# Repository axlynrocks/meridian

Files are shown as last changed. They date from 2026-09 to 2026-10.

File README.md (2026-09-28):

# meridian

note: this project is my attempt at merging my 2 biggest interests and speedrunning them in 2 months and the culmination of about half a year's worth of _severe_ procrastination

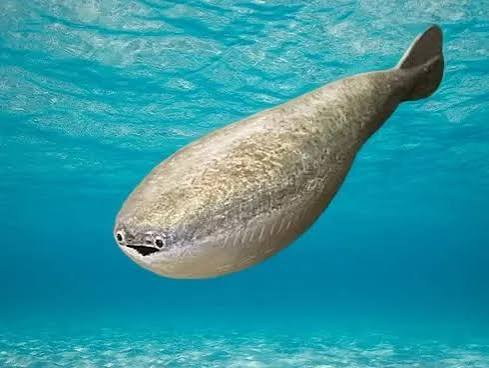
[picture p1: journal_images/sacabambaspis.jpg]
sacabambaspis


second note: no pics yet, will have them once mk. 1 is done!!!

## what is this?

a hybrid autonomous underwater research vehicle for me to use researching coastal waters!

as of meridian mk. 1, it uses 6 thrusters in total for movement: 4 for yaw and forwards / backwards movement, and 2 for roll and upwards / downwards movement. with an acrylic shell with a polycarbonate dome for its inbuilt camera as well as a couple of aluminum mounting rods attached to the exterior, i can attach practically anything i want to it (but they're mostly going to be sensors anyway) and of course, all the stuff inside like the ESCs, FC, sensor board, power management board, carrier board for the compute module are all custom made by yours truly!

> "perpetually a work in progress" - me '26

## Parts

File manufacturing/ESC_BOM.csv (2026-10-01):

part | quantity | description | cost / unit (USD) | link | datasheet | distributor | manufacturer
STM32G071KBU6N | 1*4 | MCU for BLDC control | 2.49 | https://www.st.com/en/microcontrollers-microprocessors/stm32g071kb.html | https://www.st.com/resource/en/datasheet/stm32g071kb.pdf | Digikey | STMicroelectronics
SIR696DP-T1-GE3 | 6*4 | MOSFETs | 1.71 | https://www.digikey.in/en/products/detail/vishay-siliconix/SIR696DP-T1-GE3/6707749 | https://www.vishay.com/docs/65689/sir696dp.pdf | Digikey | Vishay Siliconix
DRV8300DRGER | 1*4 | half-bridge gate driver | 0.88 | https://www.digikey.my/en/products/detail/texas-instruments/DRV8300DRGER/13918763 | https://www.ti.com/lit/ds/symlink/drv8300.pdf | Digikey | Texas Instruments
HT7550-1 | 1 | 5V voltage regulator | 0.25 | https://www.digikey.my/en/products/detail/umw/HT7550-1/17635253 | https://www.umw-ic.com/static/pdf/50f0291342dc480ca9b1da386971e0aa.pdf | Digikey | UMW
HT7533-1 | 1 | 3.3V voltage regulator | 0.25 | https://www.digikey.my/en/products/detail/umw/HT7533-1/17635239 | https://www.umw-ic.com/static/pdf/50f0291342dc480ca9b1da386971e0aa.pdf | Digikey | UMW
INA180A1IDBVR | 1*4 | current sense amplifier | 0.82 | https://www.digikey.com/en/products/detail/texas-instruments/INA180B1IDBVR/8105876 | https://www.ti.com/lit/ds/symlink/ina180.pdf | Digikey | Texas Instruments
1N4148W-HG3_A-08 | 3*4 | diode | 0.5 | https://www.digikey.com/en/products/detail/vishay-general-semiconductor-diodes-division/1N4148W-HG3-A-08/22145563 | https://www.vishay.com/docs/86357/1n4148w-g.pdf | Digikey | Vishay
TPS7A4501KTTR | 1 | adjustable voltage regulator | 3.7 | https://www.digikey.my/en/products/detail/texas-instruments/TPS7A4501KTTR/1908606 | https://www.ti.com/lit/ds/symlink/tps7a45.pdf | Digikey | Texas Instruments

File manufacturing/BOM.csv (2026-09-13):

part | quantity | description | cost / unit (USD) | link | datasheet | distributor | manufacturer
DFR1146 | 1 | SBC | 192.5 | https://www.digikey.my/en/products/detail/dfrobot/DFR1146/23028653 | https://docs.lattepanda.com/content/mu_edition/introduction/ | DigiKey | DFRobot
custom PCBs | 1 | to hold all the parts | ~400 | https://jlcpcb.com/ | N/A | JLCPCB | JLCPCB
BR-101052-200 | 1 | acrylic tube 200mm len. | 170 | https://bluerobotics.com/store/watertight-enclosures/locking-series/wte-locking-tube-r1-vp/ | https://bluerobotics.com/wp-content/uploads/2026/05/WTE-DATASHEET-RevC.5-MAY2026.pdf | BlueRobotics | BlueRobotics
BR-100495 | 2 | clear polycarbonate dome | 42 | https://bluerobotics.com/store/watertight-enclosures/locking-series/wte-end-cap-vp/ | https://bluerobotics.com/wp-content/uploads/2026/05/WTE-DATASHEET-RevC.5-MAY2026.pdf | BlueRobotics | BlueRobotics
BR-100665 | 1 | o-ring flange | 50 | https://bluerobotics.com/store/watertight-enclosures/locking-series/wte-flange-vp/ | https://bluerobotics.com/wp-content/uploads/2026/05/WTE-DATASHEET-RevC.5-MAY2026.pdf | BlueRobotics | BlueRobotics
BR-102993-002 | 1 | aluminum end cap 10x M10 | 42 | https://bluerobotics.com/store/watertight-enclosures/locking-series/wte-end-cap-vp/ | https://bluerobotics.com/wp-content/uploads/2026/05/WTE-DATASHEET-RevC.5-MAY2026.pdf | BlueRobotics | BlueRobotics
BR-100804 | 1 | pressure relief valve | 32 | https://bluerobotics.com/store/watertight-enclosures/enclosure-tools-supplies/prv-m10-asm/ | https://bluerobotics.com/wp-content/uploads/2026/05/WTE-DATASHEET-RevC.5-MAY2026.pdf | BlueRobotics | BlueRobotics
BR-100574 | 1 | o-ring pick | 0 | https://bluerobotics.com/store/watertight-enclosures/enclosure-tools-supplies/tool-o-ring-pick-r1/ | https://bluerobotics.com/wp-content/uploads/2026/05/WTE-DATASHEET-RevC.5-MAY2026.pdf | BlueRobotics | BlueRobotics
BR-103290-200 | 2 | narrow rails 200N | 29 | https://bluerobotics.com/store/watertight-enclosures/locking-series/watertight-enclosure-rails-set/ | https://bluerobotics.com/wp-content/uploads/2025/01/WTE-RAILS-DATASHEET-RevA-FEB2025.pdf | BlueRobotics | BlueRobotics
BR-103291-400 | 1 | rect. tray | 24 | https://bluerobotics.com/store/watertight-enclosures/locking-series/watertight-enclosure-rectangular-tray/ | https://bluerobotics.com/wp-content/uploads/2025/01/WTE-RAILS-DATASHEET-RevA-FEB2025.pdf | BlueRobotics | BlueRobotics
BR-103292-400 | 3 | circ. tray | 27 | https://bluerobotics.com/store/watertight-enclosures/locking-series/watertight-enclosure-circular-tray/ | https://bluerobotics.com/wp-content/uploads/2025/01/WTE-RAILS-DATASHEET-RevA-FEB2025.pdf | BlueRobotics | BlueRobotics

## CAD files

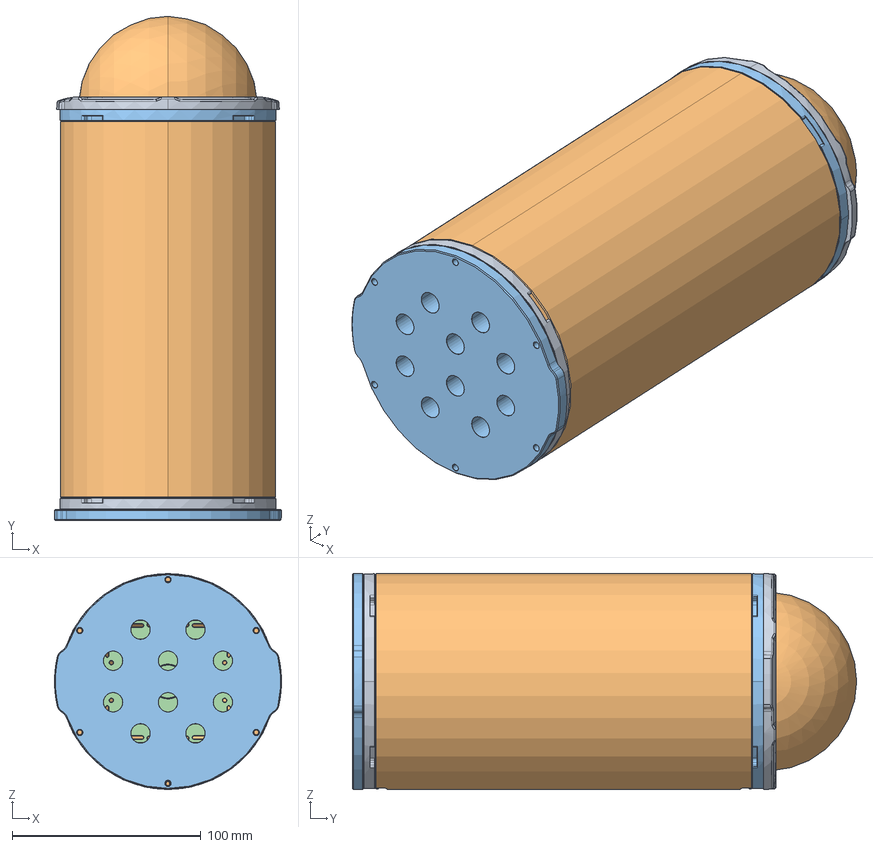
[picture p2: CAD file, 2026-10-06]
hardware/200_x_100mm_auv_hull.FCStd
120.3 x 267.3 x 114.5 mm
WTE4-P-DOME-RETAINING-RING-R1
WTE4-P-DOME-R4
BR-101040_RevC_1
BR-103131-400_Rev_2
BR-102784-200_Rev_1_1
BR-102784-200_Rev_1_2
BR-103130-400_Rev_2_1
BR-103130-400_Rev_2_2
BR-101040_RevC_2
BR-101052-200_RevB
WTE4-END-CAP-10XM10-R2

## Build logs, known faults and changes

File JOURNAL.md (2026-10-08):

---
title: "meridian"
author: "axie"
description: "a modular AUV"
created_at: "2026-09-13"
---

# september 13: one small commit for me, one giant leap for PROJECTKIND!!!

oookie so i made the repo, added the base stuff: a README, the JOURNAL you're lookin at rn, kicad project files, and the BOM

note: pitching in slack as t1, i hope i get accepted!!! (my plan B's to make this a t2 and upgrade after)

this project is going to have mutiple versions adding features successively, more on this later,

version 1 is only going to include the base AUV, SLAM, and water sampling

the base AUV's going to include 4 main PCBs

1. the main board with the SBC and breakouts to other peripherals and boards,
2. a motor controller board for movement and attachments (eg. robotic arms, water sampling),
3. a sensor controller board to process raw sensor input before feeding it into the SBC, and
4. a battery management board to control charging and power distribution

its hull will be made out of an acrylic tube (or tubes), O-rings, hemispheres on the front and back, and include some rails along its side for the modular attachments

the SLAM (aka. simultaneous localization & mapping), will use an array of sonar transceivers and a BLDC motor sweeping across a certain area underneath the AUV to map its surroundings
sonar array

the water sampling will use a peristaltic pump to extract water from its surroundings into a chamber for later analysis

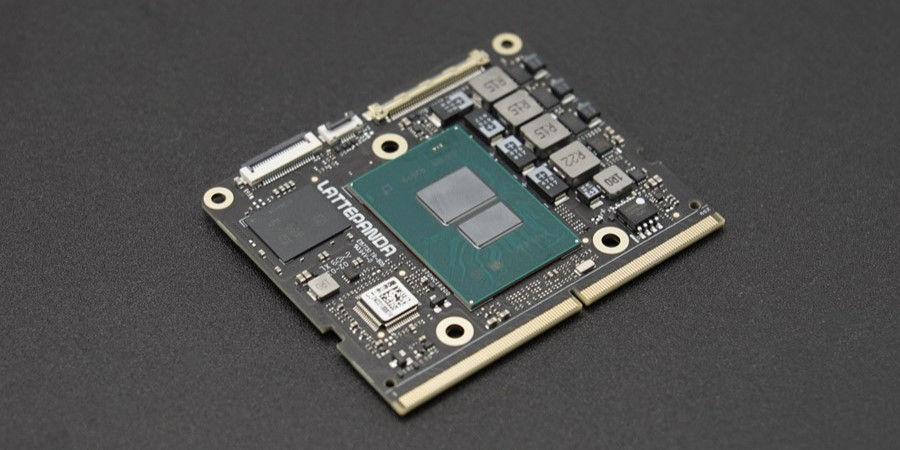
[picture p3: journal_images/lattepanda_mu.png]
picture of the LattePanda Mu stolen from the LattePanda docs site


(very) rough BOM: (for v1)
note: the stuff listed here includes the base AUV, water sampling, and recharging
hull and other enclosure bits: about 300

- SBC (lattepanda mu): 190
- mounting rods: 10\*4
- breakout PCBs: 50 (not including components
- gyro: 10
- depth sensor: 80
- propeller w motor: 30
- assorted CNC / 3D printed stuff (eg propellers, attachment parts, internal frames): about 100
- battery packs: 40
- camera: 50
- water sampling stuff - stepper motor: 15, tubes and chamber: 50
- recharging stuff - solar panels: 50
  wires and watertight connectors: 30

**total time spent: 2.2 hours**

# september 13: researching AUV components: enclosure edition

continuing to research the parts and features i'll have here to get a more accurate BOM with all the components i'll need for v1!

i'm planning to waterproof the hull (just the hull, not the arm or anything else, i wanna do that _myself_) with the following [watertight enclosure components from BlueRobotics](https://bluerobotics.com/store/watertight-enclosures/wte-vp/) ([datasheet](https://bluerobotics.com/wp-content/uploads/2026/05/WTE-DATASHEET-RevC.5-MAY2026.pdf)) also all the following BlueRobotics parts are for a 100mm dia. AUV

| part | quantity | description | cost / unit (USD) |
| --- | --- | --- | --- |
| BR-101052-200 | 1 | acrylic tube 200mm len.  | 170 |
| BR-100495 | 1 | clear polycarbonate dome | 42 |
| BR-100665 | 2 | o-ring flange | 50 |
| BR-102993-002 | 1 | aluminum end cap 10x M10 | 42 |
| BR-100804 | 1 | pressure relief valve | 32 |
| BR-100574 | 1 | o-ring pick | 0 |

total cost: 386

as well as their [RAILS set](https://bluerobotics.com/store/watertight-enclosures/locking-series/watertight-enclosure-rails/) ([datasheet](https://bluerobotics.com/wp-content/uploads/2025/01/WTE-RAILS-DATASHEET-RevA-FEB2025.pdf))

| part | quantity | description | cost / unit (USD) |
| --- | --- | --- | --- |
| BR-103290-200 | 2 | narrow rails 200N | 29 |
| BR-103291-400 | 1 | rect. tray | 24 |
| BR-103292-400 | 3 | circ. tray | 27 |

~~| BR-103293 | 10 | 3 | mounting screws |~~
~~note: amount of screws is 4x / rect. tray, 2x / circ. tray~~

note: i realized the screws to connect the RAILS parts are included, and the mounting screws mentioned are generic phillips screws

total cost: 163

however...

i'm kinda broke so i might proceed to use the CAD models provided to make custom versions and 3D print them... i should ask BlueRobotics first (personally i don't exactly want to get in legal trouble for violating some kinda copyright law)

sooooo....

i went ahead and asked them if their files were open-source and available to 3D print, and i may or may not also have asked if i could get some parts free (i'm hoping they say yes to both or at least one of them!!!)

note: the 3D models are available under `technical details > 3D models` in their respective product pages

anywho, continuing to look at JLC3DP and JLCCNC quotes for the watertight enclosure parts, the cheapest functional quotes i could get are the following:

| 3D file: | WTE4-P-DOME-RETAINING-RING-R1.STEP |
| --- | --- |
| Dimensions: | 11.45×11.45×0.65cm |
| Volume: | 13.1 cm3 |
| Surface Area: | 103.95 cm2 |
| 3D Technology:  | SLA(Resin) |
| Material: | 9600 Resin |
| Colors: | White |
| Surface Finish: | 01 Sanding, General Sanding |
| Thread: | No thread |
| Build Time: | 3 days |
| Gross Weight: | 0.02 kg |
| Package Box: | With JLC3DP Logo |
| Qty: | 1 |
| Product Decs: | Plastic Enclosure -HS Code 392690  |

BR-100495 retaining ring for $1.19

| 3D file: | BR-101052-200_RevB.STEP |
| --- | --- |
| Dimensions: | 20×11.43×11.43 cm |
| Volume: | 406.6 cm3 |
| Surface Area: | 1392.47 cm2 |
| 3D Technology:  | SLA(Resin) |
| Material: | 9600 Resin |
| Colors: | White |
| Surface Finish: | 01 Sanding,General Sanding |
| Thread: | No thread |
| Build Time: | 3 days |
| Gross Weight: | 0.74 kg |
| Package Box: | With JLC3DP Logo |
| Qty: | 1 |
| Product Decs: | Plastic Enclosure -HS Code 392690 |

BR-101052-200 for $39.68

| 3D file: | WTE4-M-END-CAP-10XM10-R2.step |
| --- | --- |
| Dimensions: | 11.43×11.43×1cm |
| Volume: | 78.6 cm3 |
| Surface Area: | 257.25 cm2 |
| 3D Technology:  | SLA(Resin) |
| Material: | 9600 Resin |
| Colors: | White |
| Surface Finish: | 01 Sanding, General Sanding |
| Thread: | No thread |
| Build Time: | 3 days |
| Gross Weight: | 0.14 kg |
| Package Box: | With JLC3DP Logo |
| Qty: | 1 |
| Product Decs: | Plastic Enclosure -HS Code 392690 |

BR-102993-002 for $7.15

| 3D file: | BR-101040_RevC.step |
| --- | --- |
| Dimensions: | 11.43x11.43×2.7cm |
| Volume: | 38.71 cm3 |
| Surface Area: | 294.7 cm2 |
| 3D Technology:  | SLA(Resin) |
| Material: | 9600 Resin |
| Colors: | White |
| Surface Finish: | 01 Sanding, General Sanding |
| Thread: | No thread |
| Build Time: | 3 days |
| Gross Weight: | 0.14 kg |
| Package Box: | With JLC3DP Logo |
| Qty: | 2 |
| Product Decs: | Plastic Enclosure -HS Code 392690 |

BR-100665 without o-rings or locking cord system for $3.52 ($3.52 \* 2 = $7.04)

| 3D file: | WTE4-P-DOME-R4.step |
| --- | --- |
| Dimensions: | 104.66 x 104.66×49.3mm |
| Volume: | 54875.32 mm3 |
| Qty: | 1 |
| Material: | Polycarbonate |
| Surface Finish: | Blue-Tinted Vapor Polishing |
| Tightest Tolerance: | ISO 2768 medium |
| Appearance Requirements: | Standard |
| Threads: | No |
| Sub-assembly: | No |
| Product Desc: | plastic End Cap - HS Code 392350 |
| Build Time: | 6 days |
| Gross Weight: | 0.14kg |
| CNC Remark: | - |

BR-100495 clear polycarbonate dome for 89.30

JLC estimates the price of the aforementioned parts at a merchandise total of $144.36 and an estimated shipping fee of $9.78 with UPS Worldwide Express Saver bringing the watertight enclosure's subtotal to $154.14

as for the RAILS parts (excluding screws):

| 3D file: | BR-102784-200_RevA.step |
| --- | --- |
| Dimensions: | 14.9×1.5×0.62cm |
| Volume: | 4.99 cm3 |
| Surface Area: | 57.59 cm2 |
| 3D Technology:  | SLA(Resin) |
| Material: | 9600 Resin |
| Colors: | White |
| Surface Finish: | 01 Sanding, General Sanding |
| Thread: | No thread |
| Build Time: | 3 days |
| Gross Weight: | 0.02 kg |
| Package Box: | With JLC3DP Logo |
| Qty: | 2 |
| Product Decs: | Plastic Connectors -HS Code 392690 |

BR-103290-200 for $0.45 ($0.45 \* 2 = $0.90)

| 3D file: | BR-103130-400_RevB.step |
| --- | --- |
| Dimensions: | 8.7×6.8×0.6cm |
| Volume: | 28.55 cm3 |
| Surface Area: | 134.47 cm2 |
| 3D Technology:  | SLA(Resin) |
| Material: | 9600 Resin |
| Colors: | White |
| Surface Finish: | 01 Sanding, General Sanding |
| Thread: | No thread |
| Build Time: | 3 days |
| Gross Weight: | 0.05 kg |
| Package Box: | With JLC3DP Logo |
| Qty: | 1 |
| Product Decs: | Plastic Base Plate -HS Code 392690 |

BR-103291-400 for $2.6

| 3D file: | BR-103131-400_RevB.step |
| --- | --- |
| Dimensions: | 9.85×9.3×0.6cm |
| Volume: | 35.43 cm3 |
| Surface Area: | 181.27 cm2 |
| 3D Technology:  | SLA(Resin) |
| Material: | 9600 Resin |
| Colors: | White |
| Surface Finish: | 01 Sanding, General Sanding |
| Thread: | No thread |
| Build Time: | 3 days |
| Gross Weight: | 0.19 kg |
| Package Box: | With JLC3DP Logo |
| Qty: | 3 |
| Product Decs: | Plastic Base Plate -HS Code 392690 |

BR-103292-400 for $3.22 (@3.22 \* 3 = $9.66)

JLC estimates the price of the aforementioned parts at a merchandise total of $13.16 and an estimated shipping fee of $6.74 with E-POST bringing the RAILS system subtotal to $19.90

note: on all of the JLCCNC parts listed here, you'll see ISO 2768 medium listed for the tolerances. that means that they follow [this standard](https://jlccnc.com/help/article/iso-2768-tolerance-standards-for-cnc-machining) and for most of the parts, they fall below the over 400 up to 1000 range for nominal lengths which are tighter than most of the equivalent parts cast acrylic variants straight from BlueRobotics at about +-2mm, but their aluminum variants have a roughly equivalent tolerance. however, the only part listed above getting CNCed is the polycarbonate dome, whose original tolerance is +-0.1mm which is tighter than the ISO 2768 medium tolerance so i just wasted a minute of your time lmao

another, more serious note: i asked around on the HC slack about if this would be alright to use, and what i got was more or less the following: i can use them, but it reduces complexity, and a t1 project needs to be pretty complex. so what i'm going to do is go ahead with it (because at the moment i'm just researching and then making the PCBs) while waiting for BlueRobotics' response

added the above BlueRobotics components to the BOM for now

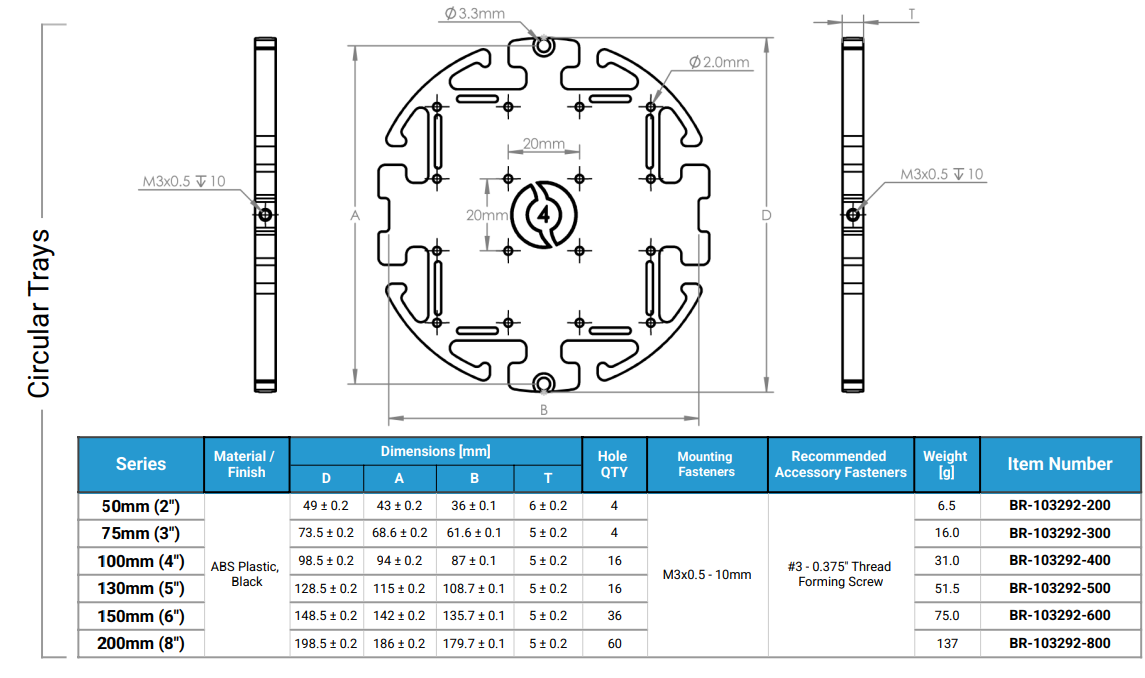
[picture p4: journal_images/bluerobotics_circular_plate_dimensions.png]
BlueRobotics circular plate dimensions


for the circular plates, each one can hold a maximum ~6x6cm PCB, based on its mounting holes on each side, flat against the plate if single sided, but will require standoffs or spacers if double sided

also, i looked around for connectors and i might consider using Samtec AccliMate connectors with an IP68 rating, but more on that later

note: just realized .csv files were included in the gitignore, removed that

**total time spent: 2.05 hours**

# september 14: researching AUV components: thruster edition pt.1

note: i'm planning to change both the hull, external structure, and thrusters in a future version, v1's going to be a pretty minimal version of the whole AUV

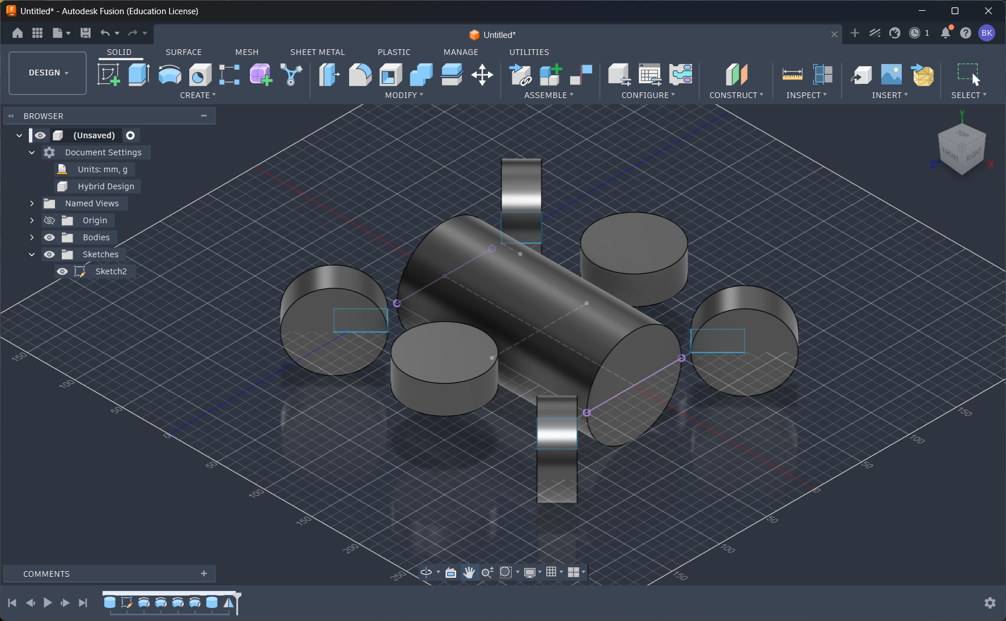
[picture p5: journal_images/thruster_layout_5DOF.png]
thruster layout for 5 DOF


they're going to be in a cross-like formation with 2 xtra thrusters in the middle for movement in the z axis, stabilization, and roll, giving the AUV a total of 5 DOF, 3 translation and 2 rotation

**total time spent: 1 hour**

# september 15: researching AUV components: thruster edition pt.2 (abridged)

note: BlueRobotics replied, i'll be contacting their sales dept. to see if i can score a couple of free samples hehe >:3c

i looked at some designs for how to design the [thrusters](https://en.wikipedia.org/wiki/Underwater_thruster) and what i came back with was mostly that sealing anything with that many moving parts gets inefficient and hard way too fast. instead, there are 2 main methods for motors underwater: completely filling any cavities with mineral oil, _preventing_ water from seeping into the motor, or only completely sealing certain electrically active parts like connectors and control boards, leaving the motor itself with its stator and rotor in direct contact with water.

so instead of custom designing a thruster, right now i'm looking for thrusters and motors i can buy to use for the propulsion (and potentially other appendages)

found this: the [APISQUEEN U2 MINI 1.3Kg Underwater Thruster 16V 130W](https://www.underwaterthruster.com/products/apisqueen-u2-mini-1-3kg-underwater-thruster-16v-130w) for $25 each, the only drawback (for this and other thrusters) is that in order to use these, i'll have to strip the connector off for the cable to fit into the [cable penetrators](https://bluerobotics.com/store/cables-connectors/penetrators/wetlink-penetrator-jpt/) on the back of the AUV

there's also this [motor](https://www.underwaterthruster.com/products/waterproof-brushless-motor-100w-2418-corrosion-and-oxidation-resistant-for-use-in-underwater-robots-rovs-unmanned-boats-e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) which i think would be a good choice for the arm, MSIS SLAM or the tether.

i really would like to custom build a thruster like the [T200](https://bluerobotics.com/store/thrusters/t100-t200-thrusters/t200-thruster-r2-rp/), maybe in v2

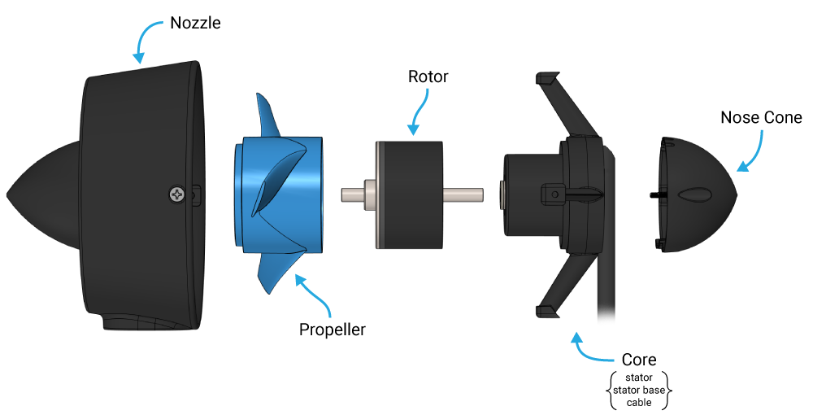
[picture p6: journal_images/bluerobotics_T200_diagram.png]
BlueRobotics T200 diagram


note: no lapse this time, did this throughout the day in class :<

**total time spent: 1 hour**

# september 16: researching AUV components: subsystem module component edition pt.1 ft. external structure

the external structure is going to be comprised of 4 aluminum rods arranged around and parallel to the hull, for the external sensors and other peripherals to be connected, considering making the brackets connecting the rods to the hull out of something FDM printed for increased structural stability, as opposed to SLA specifically because this doesn't need to be waterproof (also have to look at infill patterns more later)

about the thrusters, in order to offload movement and stabilization tasks i'll have to include 8 independent ESCs on the propulsion control module and maybe a gyro/accelerometer for dead reckoning with it (before you ask, yes i'm too broke to afford a DVL, no i don't think it's crucial for navigation _yet_)

looking at the ST website (aka. glorified ads) for [motor control related stuff](https://www.st.com/content/st_com/en/ecosystems/stm32-motor-control-ecosystem.html), i'm considering integrating one of those into the propulsion control module to reduce overhead and get something maybe like realtime stabilization

due to the limited space constraints i'll be separating the propulsion control module from the peripheral motor control module (also i have to figure out the optimal placement for the components to not overheat)

some the sensors will be located on the sensor control module, however most of the sensors have to be situated on the external rods via a bar clamp mount similar to [this commercially available one](https://www.bulletpointmountingsolutions.com/products/quick-adjust-bar-clamp-mount-with-20mm-connector-end-nubby-edition-fits-0-5-to-2-bars)

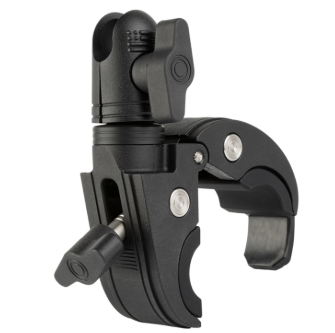
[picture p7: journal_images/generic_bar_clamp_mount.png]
a generic commercially available bar clamp mount


as the objective of this whole system is that everything remains completely modular. i'll also need to kinda think about sealing modules outside the hull with o-rings or something, i was thinking of FDM printing rectangular TPU o rings for the exterior modules similar to how the hull's structured, but maybe with a hinged cover instead.

the sensors that could be located inside besides those already mentioned above (which tbh are just the gyro and accelerometer) include a magnetometer (will have to consider its placement relative to the motors and other sources of magnetic interference) a temperature sensor to check if it's overheating, and leakage sensors around the hull's interior and cable penetrators (to make sure i don't end up frying my hardware :p)

on the other hand, the ones that i'm thinking of placing outside (most likely in v2) are a hydrophone, underwater optical / acoustic communication, a DVL, water

note: i'm just going to go ahead and include an MCU on each subsystem to keep the load off of the compute module

the power management module's going to have to manage recharging and communicate with the other modules for a whole lot of power saving optimizations and stuff. for v1, i'm going to include solar cells on the top of the hull for it to recharge when surfacing on low power. one major challenge however is the fact that the batteries used will generate a _considerable_ amount of heat and i'll need to figure out a way to cool it (or i might push that to v2)

note: went afk for a bit to get some tea

now for the thing that will (admittedly) probably be the single most challenging part of this design: the carrier module (note that i am NOT good at making high-speed PCBs, but you know what they say, "make it exist now, make it perfect later")

the compute module carrier's going to be based around the LattePanda Mu and have external storage,

TBC

**total time spent: 1 hour**

# september 17: researching AUV components: subsystem module component edition pt.2

the compute module carrier's going to be based around the LattePanda Mu, have external storage and all the GPIO connectors i'll possibly need to connect it with other stuff

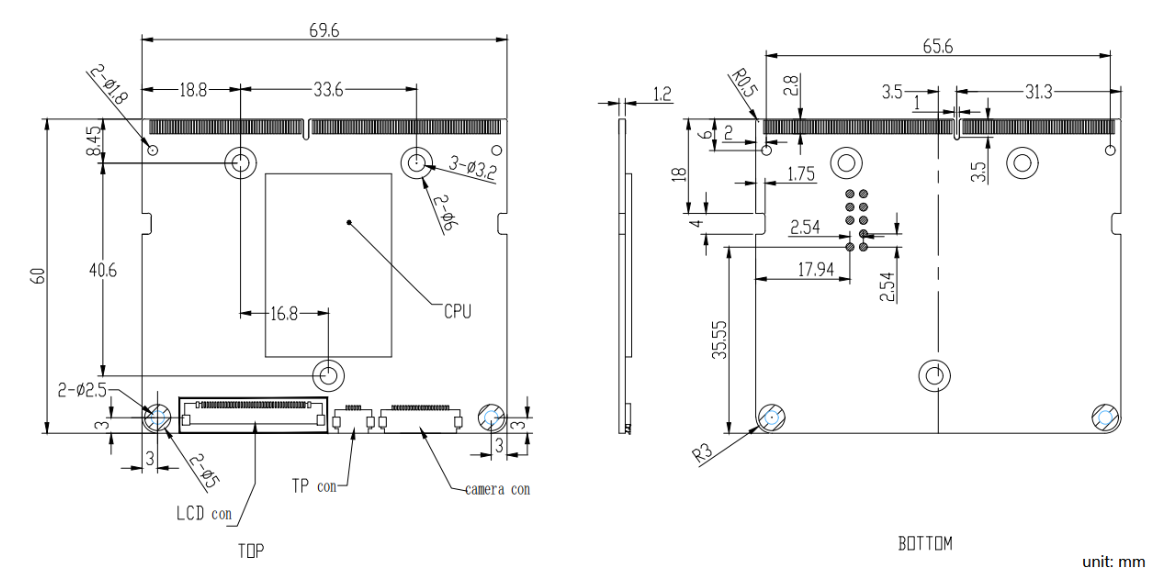
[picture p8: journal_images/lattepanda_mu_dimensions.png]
LattePanda Mu dimensions


note: i realized that the Mu's dimensions won't fit in the roughly 60\*60mm space provided by the 100mm circular plate, so i have the choice of either using a rectangular plate (sacrificing density) or increasing the diameter (and the price) of the AUV hull

i'll be basing my carrier off of [these resources](https://github.com/LattePandaTeam/LattePanda-Mu) kindly provided by the LattePanda team! i'm going through the docs to get a brief understanding of the pinout and other requirements before designing the carrier board

for the edge connector it uses a standard 260 pin DDR4 SODIMM one with at least >5.2mm clearance to accomodate for retention screws and other passive components, and it's also recommended to use SMD M2 standoffs to secure the compute module to the carrier

for the power supply, it mentions that its min voltage is 9V, its max is 20V with the typical voltage at either 12 or 15V, and that the recommended wattage varies with the 2 processors used (the DFR1146 uses an Intel N100, at >10W with a minimum 50% margin)

the rest of the details i'll figure out in due time while making the carrier board cos right now i'm thinking about how to connect all the boards and their peripherals.

note: if you're wondering why i'm spending so much time researching stuff and not making stuff yet is cos i'm tryna get a complete understand of what i'm workin with here (also listen to this [bossa nova playlist](https://www.youtube.com/watch?v=aZyxGDfXXl8))

note: forgot to push yesterday TwT

**total time spent: 1.1 hours**

# september 18: researching AUV components: enclosure edition pt.2 (the sequel)

so considering the size of the internal components, i'm thinking of increasing the AUV's diameter to the 130mm dia. 300mm len. model, with the rest remaining mostly the same, just with diff. dimensions to fit the new hull (and for some reason it's only available in aluminum i liked the acrylic one more ;A;)

| part | quantity | description | cost / unit (USD) |
| --- | --- | --- | --- |
| BR-106280-300 | 1 | aluminum tube 300mm len. | 210 |
| BR-102597 | 1 | clear polycarbonate dome | 95 |
| BR-102200 | 2 | o-ring flange | 125 |
| BR-102203-002 | 1 | aluminum end cap 5x M14, 5x M10 | 71 |
| BR-100804 | 1 | pressure relief valve | 32 |
| BR-100574 | 1 | o-ring pick | 0 |

bringing its subtotal to $658 (idt i can afford this...)

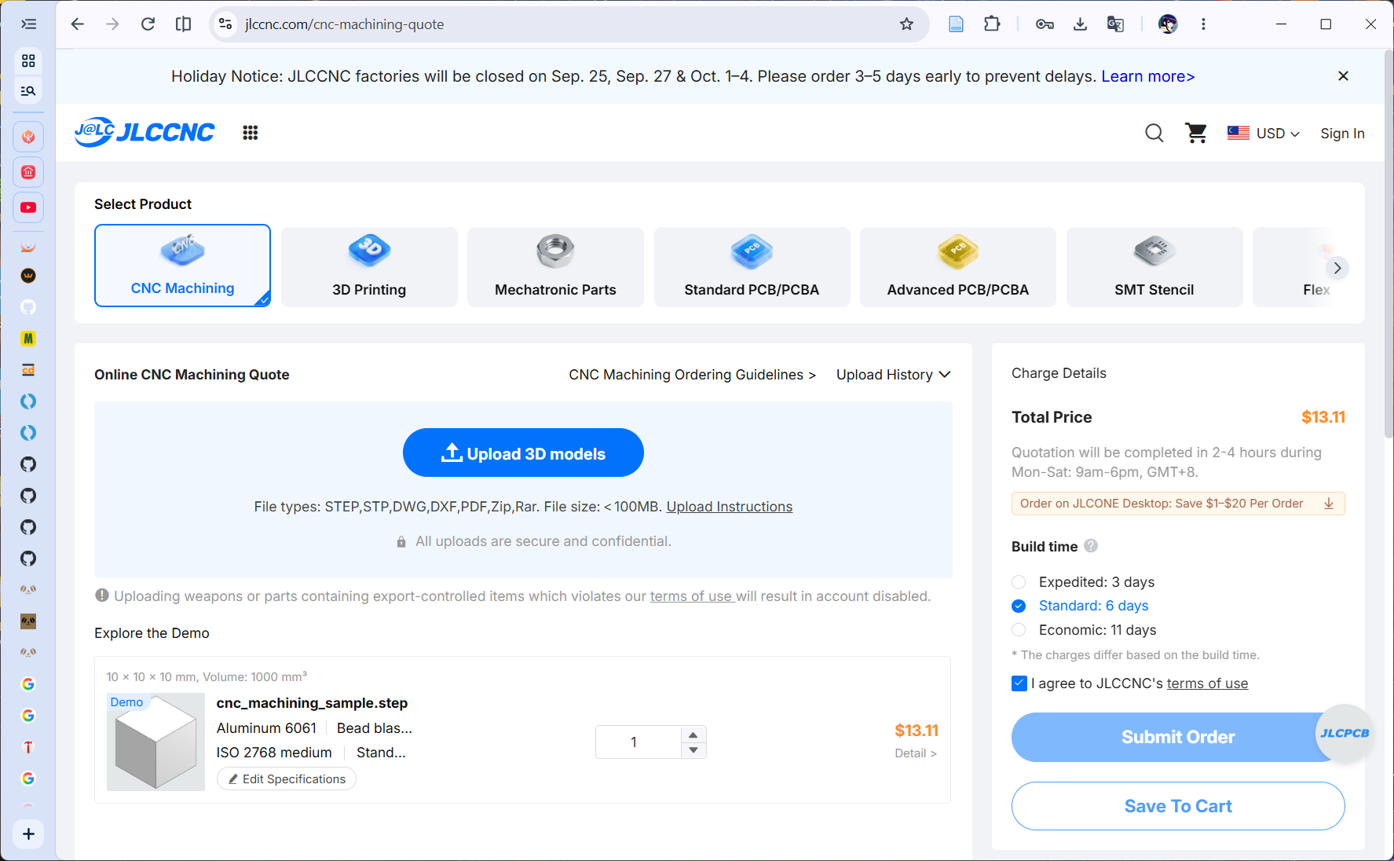
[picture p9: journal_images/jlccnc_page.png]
jlccnc page


at this point, i'm not totally convinced that increasing the size's the best way to go and i am highly convinced that i should be custom manufacturing _at least_ the hull

note: for anyone watching the lapse if i pause for a bit it's cos i'm staring at my ruler trying to picture how everything fits together

if i (slightly) compromise on cooling by putting the compute module and carrier right on top of the batteries (and also barely fitting it on either side of the PCB which is guaranteed to have to be double sided) with the compute module either oriented horizontally (which means that it's going to stick outside the 60mm wide PCB) or vertically

| part | quantity | description | cost / unit (USD) |
| --- | --- | --- | --- |
| BR-100495 | 1 | clear polycarbonate dome | 42 |
| BR-100665 | 2 | o-ring flange | 50 |
| BR-102993-002 | 1 | aluminum end cap 10x M10 | 42 |
| BR-100804 | 1 | pressure relief valve | 32 |
| BR-100574 | 1 | o-ring pick | 0 |

note: also lapse paused for about 15 mins here

total cost: $216 (slightly better)

TBC

**total time spent: 1 hour**

# september 19: researching AUV components: subsystem module component edition pt.3

went ahead and imported the RAILS and watertight enclosure files into fusion and realized it WOULD NOT be able to hold anything inside without a whole lot of compromises (and i get that the whole AUV design thing is inherently space constrained but still)

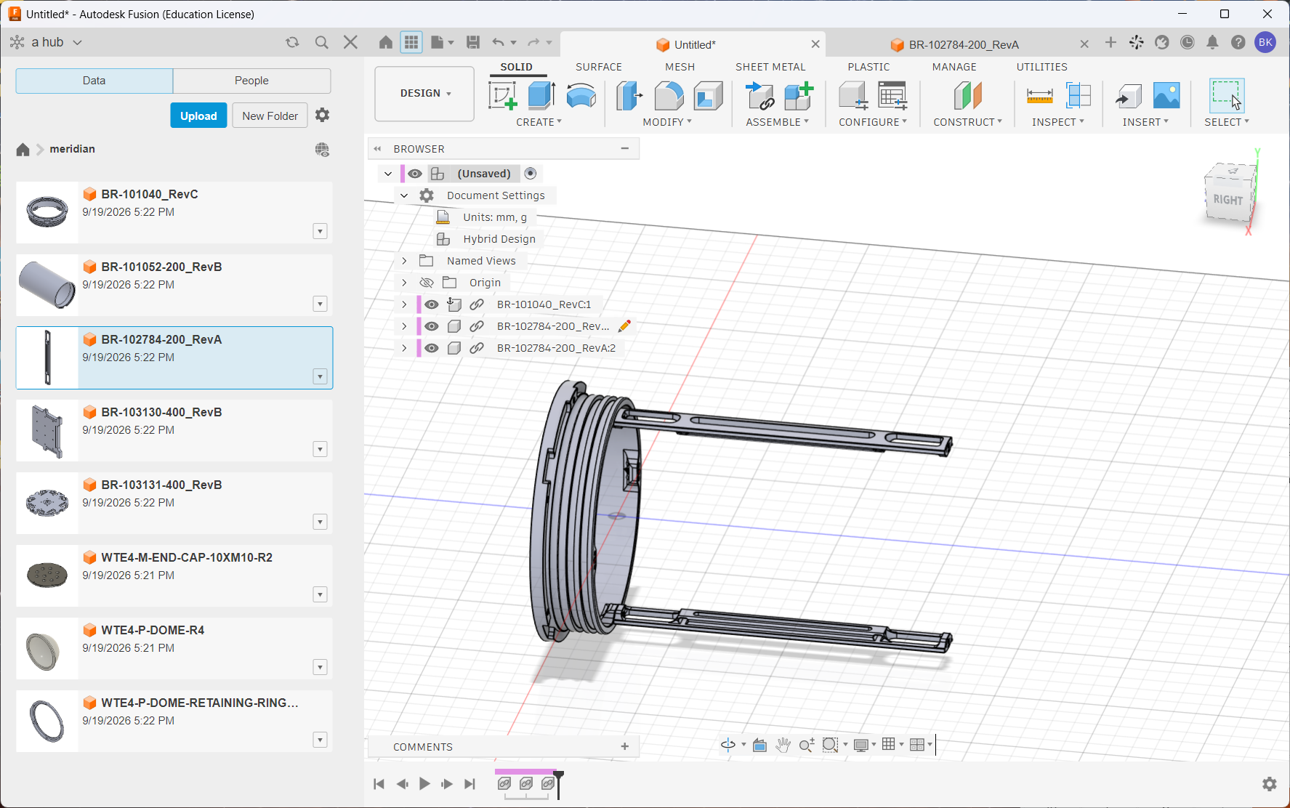
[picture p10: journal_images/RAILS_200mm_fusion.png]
cad window showing my attempt at visualizing 200mm of painful compromises


so that means i'm going with a 100mm dia. 300mm len. sized AUV, _and_ manufacturing a custom hull to fit the rods and other stuff, maybe a tether for hybrid AUV/ROV use or something

looking at the (estimated) dimensions of [this ESC PCB layout](https://deepbluembedded.com/stm32-esc-pcb-design-foc-esc-bldc-schematic/#more-10615) i'm pretty sure that i'll have to make this a double sided pcb, have multiple sections or both.

about the cable penetrators, i wasn't able to find the diameter of the [previously mentioned thruster](https://www.underwaterthruster.com/products/apisqueen-u2-mini-1-3kg-underwater-thruster-16v-130w), so i'll be switching to a different thruster (preferably one with actual documentation)

currently looking for alternative cable glands and thrusters that work together, and i've been looking at the structure of the T200 (again), where the only sealed bit's apparently the cable and stator, using a motor with an external rotor

note: looking at the [IP ratings](https://en.wikipedia.org/wiki/IP_code) and i can't exactly wrap my head around how a product or anything else really can have a rating of IP58 as the 5 means "Dust protected, Ingress of dust is not entirely prevented, but it must not enter in sufficient quantity to interfere with the safe operation of the equipment." and the 8 "Immersion, 1 meter (3 ft 3 in) or more depth". how on earth can something let dust in but not water. what.

anyways seeing as apparently all the properly documented thrusters cost more than $200 per unit i'll just have to either get something cheap(er) or make my own

time to start looking at the ESC structure, i'll be basing most of the design off of [the OpenESC-20x20](https://github.com/OpenDrone-hw/OpenESC-20x20) (also i'm more than 99% sure the website was ai generated, and i'm concerned for the schematic and PCB quality) and [this STM32 ESC PCB Design](https://deepbluembedded.com/stm32-esc-pcb-design-foc-esc-bldc-schematic/#deepdrive-stm32-esc-pcb-project-video)

most BLDCs are 3-phase, which means they'll need 3 pins per motor, and because i'll have to strip any included connectors off, i'll be using screwless side entry terminal blocks to secure the individual wires on. (not screwed ones for ease of access when in the hull)

the propulsion control module will be split into 2x 4-in-1 ESC units and a flight controller for modularity, horizontal space optimization, and most of all: **making sure i can replace them ~~if~~ when they inevitably explode**

the components of an ESC are more or less the following: (stolen from [this article](https://www.tytorobotics.com/blogs/articles/what-is-an-esc-how-does-an-esc-work))

the MCUs (one MCU per individual ESC) run firmware that controls the gate drivers which are in turn connected to the MOSFETs connected straight to the ESC terminals, track position and velocity via [back EMF modeling](https://developerhelp.microchip.com/xwiki/bin/view/applications/motors/control-algorithms/bldc/position/), and communicate back to the flight controller

TBC

**total time spent: 3.15 hours**

# september 20: researching AUV components: subsystem module component edition pt.4

note: can that thing _really_ be called a flight controller? (if not for convention, it's a swim controller at best)

the protocol (in this case preferably Cyphal, but DSHOT's fine too) is what the flight controller with its firmware (preferably Betaflight) will use to communicate with the ESCs with its firmware (preferably AM32)

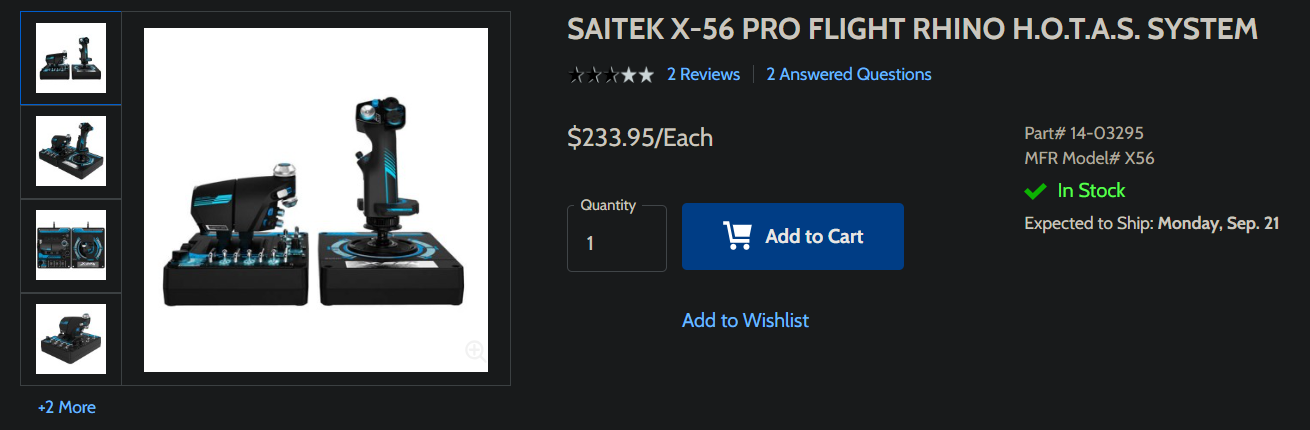
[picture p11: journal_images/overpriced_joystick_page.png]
overpriced joystick for $233.95


now the reason i'm choosing AM32 is for its larger community compared to other ESC firmware (eg. ESCape32) and the fact the BLHeli_S has been **DEAD** for the last what 4 years

might also get a joystick or somethin to control this with eventually

going to start on the ESC first and then move to the FC after, stay tuned!

note: not a lot of writing, am sick rn :< also paused lapse for 20 mins, weird commit time cos i realized i didnt push until the next day

**total time spent: 1 hour**

# september 21: designing the propulsion controller ESC pt.1

note: making this quick, got an exam to study for!

time to get to work designing the ESC!!!

according to the [Betaflight wiki](https://betaflight.com/docs/wiki/getting-started/hardware/esc-firmware#am32) it's compatible with most 32-bit MCUs, so i'll be looking for an MCU that'd be ideal for

it has to have a small enough package size to fit 4 on a board with all the MOSFETS too, maybe a UFQFPN-32 or 48 would do the job

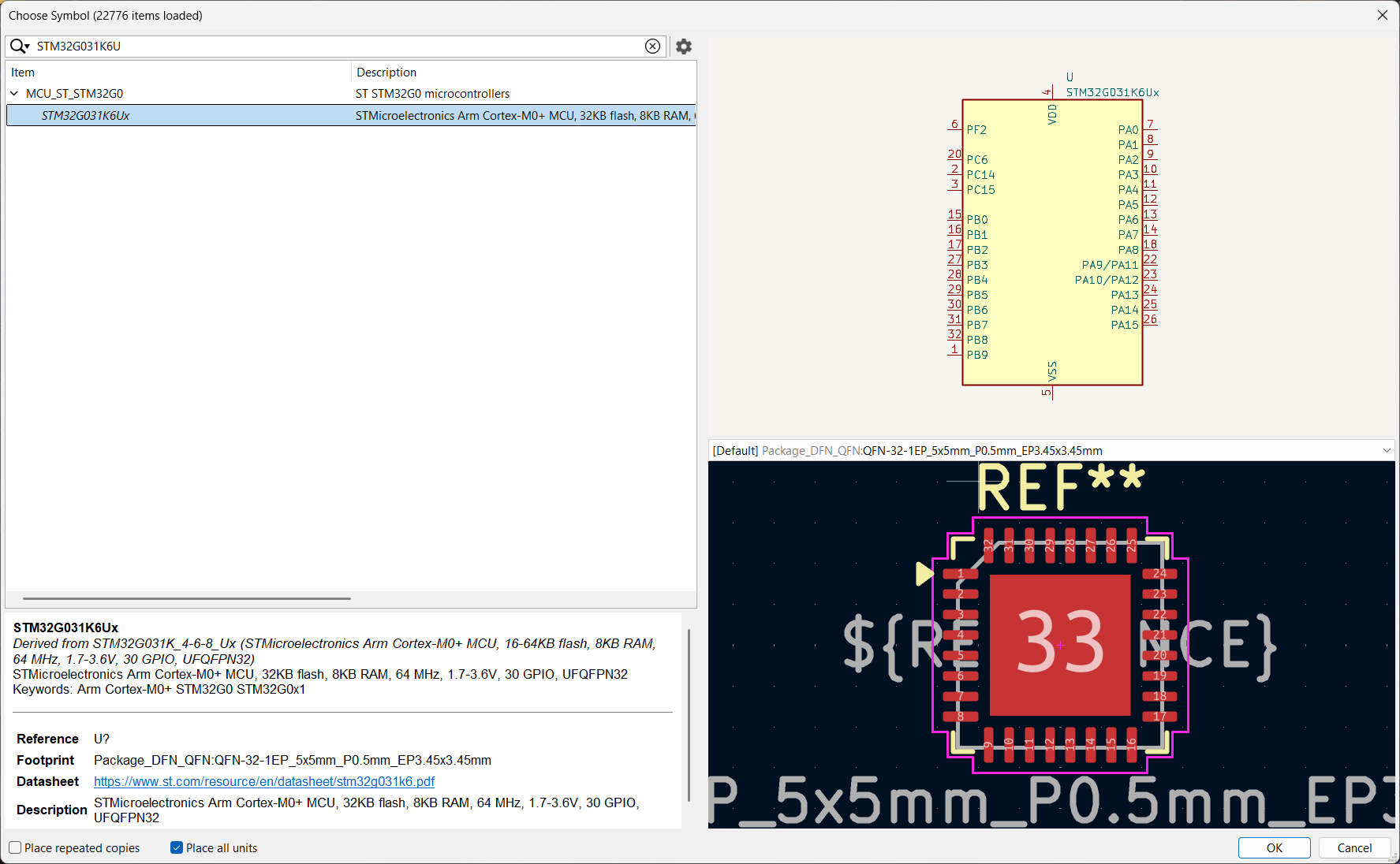
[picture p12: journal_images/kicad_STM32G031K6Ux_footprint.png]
the STM32G031K6Ux symbol and default footprint from the kicad libraries


found one (also it's family is more or less stated to be supported), the `STM32G031K6U6`, it's pretty minimal so it seems to be perfect for this job

i'm going to be designing each of the PCBs in a separate KiCad project cos it _still_ doesn't support multiboard designs

note: it happened again, weird commit time cos i realized i didnt push until the next day... hmm i really gotta remember to push

serious note to self: enough stopping half way, taking a break, and forgetting to resume lapse after that, **all entries after this MUST be properly recorded and pushed.**

**total time spent: 1.1 hours**

# september 22: designing the propulsion controller ESC pt.2

note: for the first 20 mins, i chose not to record my desktop cos i kinda maybe had a class going on :/ (if this gets deflated then oh well)

decided to use the smaller UFQFPN-28 package with a little bit more memory, the [`STM32G031G8U6`](https://www.digikey.com/en/products/detail/stmicroelectronics/STM32G031G8U6/10300275) instead to practice high density PCB routing (and to save money on build costs)

made a manufacturing folder to put the BOMs, gerbers and drill files in later for ease of access, each folder represents one module, and in the case of the propulsion control board will have 2 sets of files, one for the ESC and one for the FC (even though i'm going to have 2 ESCs on hand later)

now i'm looking at the MOSFETs i'll be using for this ESC, (again, thanks to TI for the oddly helpful guides, like [this series on MOSFETs](https://www.ti.com/lit/an/slvafg3g/slvafg3g.pdf))

note: you can find more guides like the above on [this page](https://www.ti.com/technical-documents/techdoc)

with specifically [this guide to picking MOSFETs for motor control](https://www.ti.com/lit/ta/sszt819/sszt819.pdf?ts=1790045513499) i more or less got the following: i'm going to be using a higher density package and _possibly_ one with a metal top enabling the use of a heatsink (although i'm not entirely certain how i would find 24 tiny heatsinks per board) and account for about power losses from switching and conduction (but primarily conduction)

note: each bldc has 3 phases and 2 MOSFETs per phase (see [this](https://electronics.stackexchange.com/questions/278502/why-do-bldc-escs-have-more-than-3-mosfets) for an explanation as to why) and with 4 motors that comes out to 24

i'm still kind of lost as to where to start picking MOSFETs, so i'm just looking online for some. i searched on Digikey for ones with a footprint designed for heat dissipation (in my case the PowerPAK_SO-8, it also helps that KiCad has the `PowerPAK_SO-8_Single` footprint), a 20V voltage from source to drain (which is how much it can support to drive the motor) and got the [`SIR5208DP-T1-RE3`](https://www.digikey.my/en/products/detail/vishay-siliconix/SIR5208DP-T1-RE3/25802547)

in order to flash the AM32 firmware and communicate via DSHOT with the ESC i'll need to use a connector, and i'm still a little bit lost as to what the pinout should be for the signal and other data transmission, right now i'm thinking of using a UART connection to program it (or being lazy and shoving a USB-C connector on it instead) and one wire for DSHOT, but i'm not entirely sure if this is even how it's supposed to work so uhhhhhhh back to reading...

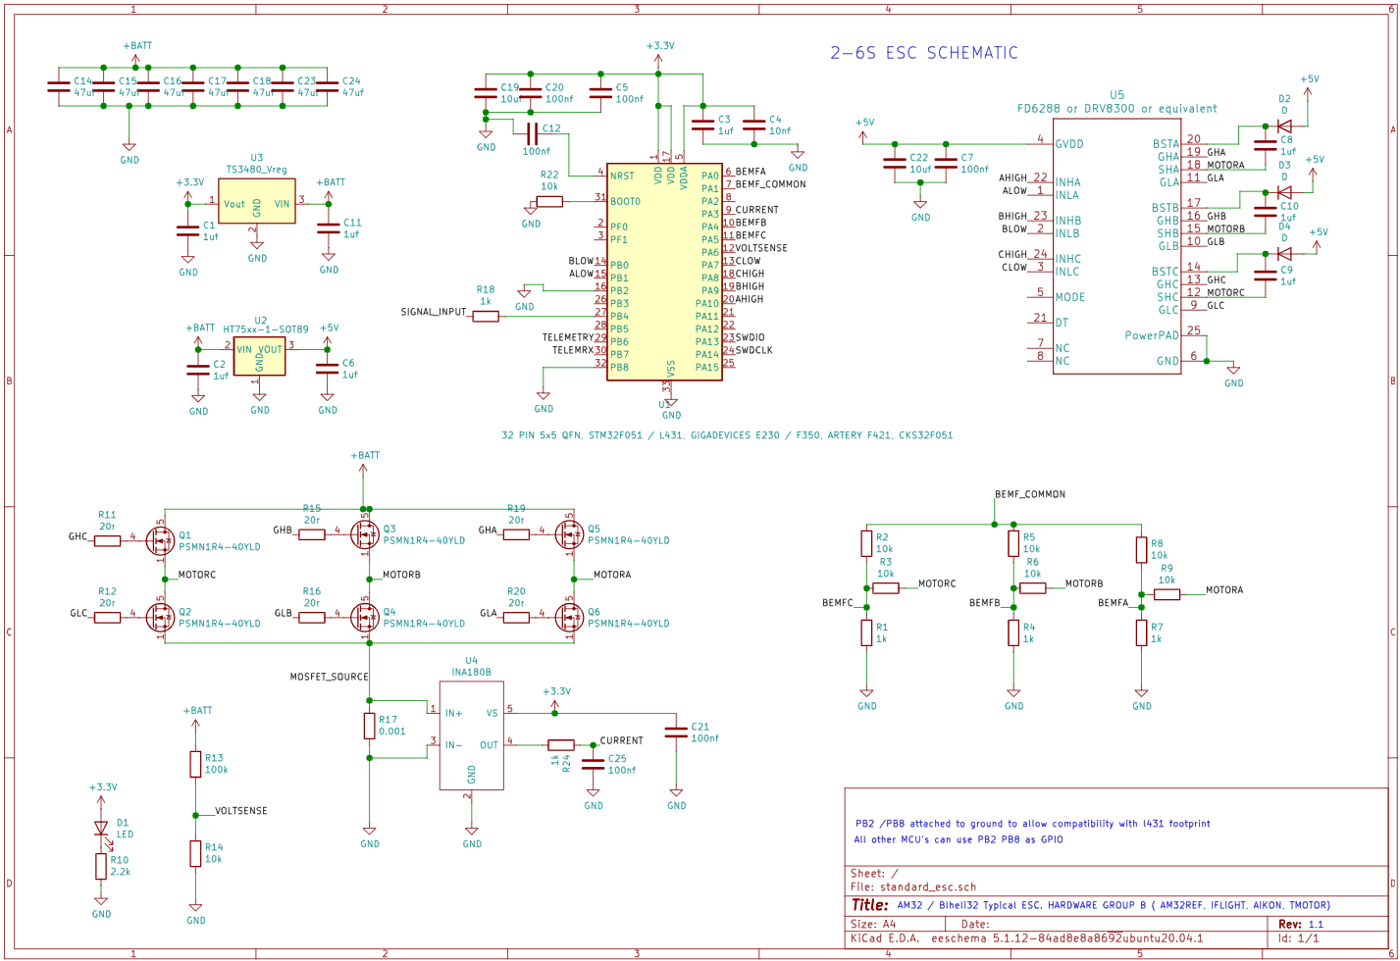
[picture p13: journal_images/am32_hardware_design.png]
neat single motor ESC design by AM32


apparently i was right (at least according to [the AM32 wiki's hardware design](https://wiki.am32.ca/development/Hardware-Design.html)), now to figure out how to bash 4 of them together on ONE PCB, probably going to refer to [this open source ESC](https://github.com/IOkFly-BLENDERIS/IOkFly-Race-AM32-4in1-ESC) cos unfortunately i don't entirely trust [OpenESC-20x20](https://github.com/OpenDrone-hw/OpenESC-20x20) (it's got AI all over, no offense to the designers though, it's not like i'm any better at making stuff lol)

might also consider somehow incorporating the FC's connector following [Betaflight standards](https://betaflight.com/docs/development/manufacturer/connector-standard)

TBC

note: put down the wrong date, sep 21 instead of sep 22

**total time spent: 1.77 hours**

# september 23: designing the propulsion controller ESC pt.3

note: there's no content here (yet) i'm just pushing this to check what happened to my 32 day streak... cos apparently it's missing so now i'm uploading all my progress to another project to see if it's a bug with the streak system or something else, also the **STILL UNAPPROVED** project shows 18.1 hours, while the other new test project shows 16.4 hours (i really need to get someone to review it ASAP like why does it even take so long it's been more than a week at this point like are we serious :/ welp what cn i do about it)

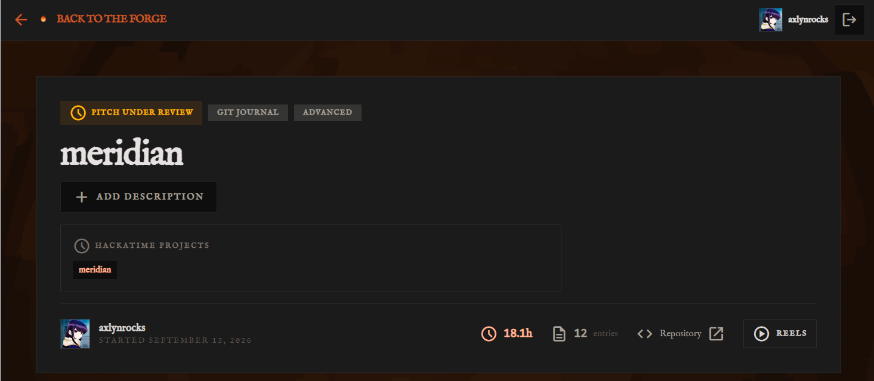
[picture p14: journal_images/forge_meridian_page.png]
me when no streak, no streak saves, and most certainly no approval :<


now for the actual stuff:

btw i rearranged the folders again cos i might have forgot about where to put the rest of the kicad project files for each (i honestly hope i don't have to rearrange them again)

this time it accounts for docs (not good ones but docs nonetheless) and the journal and each subsystem module has its own folder and project

anyways now finally back to the whole design stuff,

i'm going to be using a [`DRV8300`](https://www.ti.com/lit/ds/symlink/drv8300.pdf), specifically the [`DRV8300DRGER`](https://www.digikey.my/en/products/detail/texas-instruments/DRV8300DRGER/13918763) (and for a while i was confused as to the difference between that and the `DRV8300NRGER` and apparently the `DRV8300DRGER` has enhanced undervolatge lockout protection, or at least [that's what TI says](https://www.ti.com/compare-products/?id=12605&type=GPT&mode=alternate-opn&partList=DRV8300NRGER,DRV8300UDRGER&sticky=true))

it's also one of the listed parts in AM32's reference hardware design

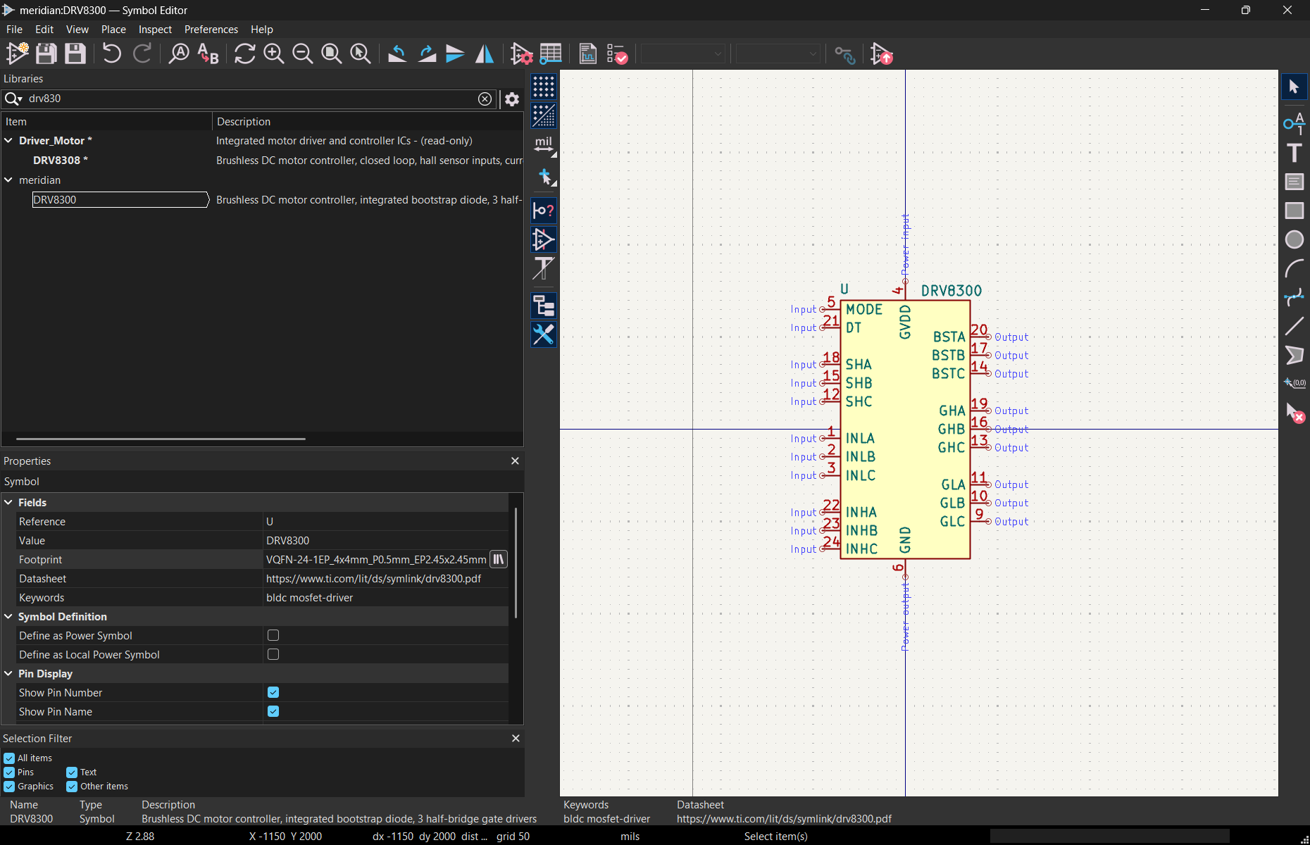
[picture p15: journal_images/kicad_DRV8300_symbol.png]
DRV8300 24 pin VQFP pinout symbol by yours truly


i made a symbol for the `DRV8300` 24-pin VQFP following the pinout listed in [the `DRV8300`'s datasheet](https://www.ti.com/lit/ds/symlink/drv8300.pdf) and attached it to the `VQFN-24-1EP_4x4mm_P0.5mm_EP2.45x2.45mm` footprint

TBC

**total time spent: 1.32 hours**

# september 27: designing the propulsion controller ESC pt.4

note: finally back after a 3 day hiatus!!! (was busy with a competition)

so i'll need one gate driver per motor, coming out to 4 of them

the other components listed in the AM32 hardware design are just a couple of voltage regulators for 3.3V and 5V power from a battery as a power source, the `TS3480CX50 RFG` and `HT7530S` respectively, as well as a `INA180B` current sense amplifer (though i'm not sure how many of those i should have)

now i'm just slightly confused on how i should wire the 4 individual ESCs together and if Betaflight supports 2x 4-in-1 ESCs

research time!

so from what i'm seeing, according to the [Betaflight connector standards]([Betaflight standards](https://betaflight.com/docs/development/manufacturer/connector-standard)

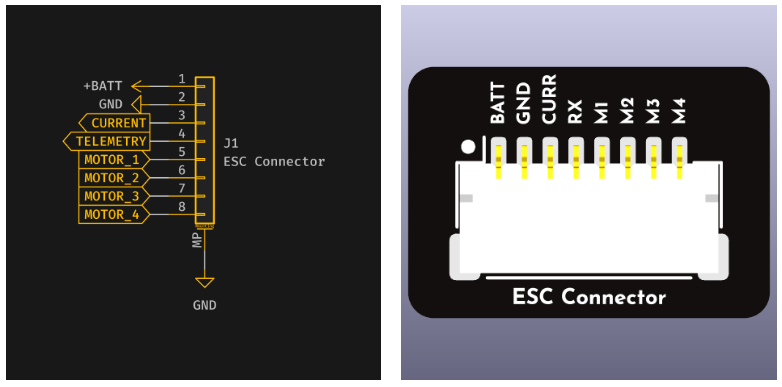
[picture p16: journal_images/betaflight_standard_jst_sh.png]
betaflight standard jst sh connector


| pin no. | signal name | description |
| --- | --- | --- |
| 1 | VBAT | power |
| 2 | GND | ground |
| 3 | current | current |
| 4 | telemetry | telemetry |
| 5 | signal 1 | motor 1 |
| 6 | signal 2 | motor 2 |
| 7 | signal 3 | motor 3 |
| 8 | signal 4 | motor 4 |

note: table stolen from betaflight wiki

- of course, there have to be 2 pins for power, `VDD` and `GND` respectively
- each motor uses 1 pin for the DSHOT signal, so a total of 4
- and these 4 motors can share 1 telemetry pin (the whole 4-in-1 thing comes from them sharing power and a board, but besides that, they don't communicate with each other and instead ac)

lookiing back at the [APISQUEEN U2 MINI 1.3Kg Underwater Thruster 16V 130W](https://www.underwaterthruster.com/products/apisqueen-u2-mini-1-3kg-underwater-thruster-16v-130w)'s specs

it takes 8A, 12-16V (about 3 to 4S LiPo) so i'll have to use some solder pads or terminal blocks supporting it instead of JST PH connectors as those only support up to 2A

now there's the problem of uploading both the firmware and the bootloader to the MCUs onboard, cos most ESCs aren't designed with [flashing either easily](https://oscarliang.com/flash-am32-blheli32-esc/) in mind, so i'll also have to include a breakout to make my job a little bit easier later, with 1x `SWD` and 1x `SWCLK` per MCU, and a common `GND` (tbh i would've just added an edge connector for the [STLINK-V3MINIE](https://www.st.com/en/development-tools/stlink-v3minie.html) but there isn't going to be enough PCB real estate to have 4 of them) probably with another JST SH connector

bringing the total connector count to 1 JST SH for connecting to the ESC, another JST SH for flashing the firmware and bootloader, 4 sets of 3 solder pads for the motors, and 2 solder pads for power.

TBC

**total time spent: 2.22 hours**

# september 28: designing the propulsion controller ESC pt.5

about the bootloader, i asked about it in the AM32 discord:

> "i'm trying to make an ESC with the STM32G071, but i'm not entirely sure which bootloader to be using, also are there any other necessary files to flash before uploading the AM32 firmware?"

note: changed the MCU _again_ cos apparently AM32 only(?) [supports a select few MCUs](https://github.com/am32-firmware/AM32#hardware) so now i'm going with the [`STM32G071KBU6N`](https://www.st.com/en/microcontrollers-microprocessors/stm32g071kb.html)

now finally, after all this hassle (and a little more waiting for a response) i can work on the schematic!

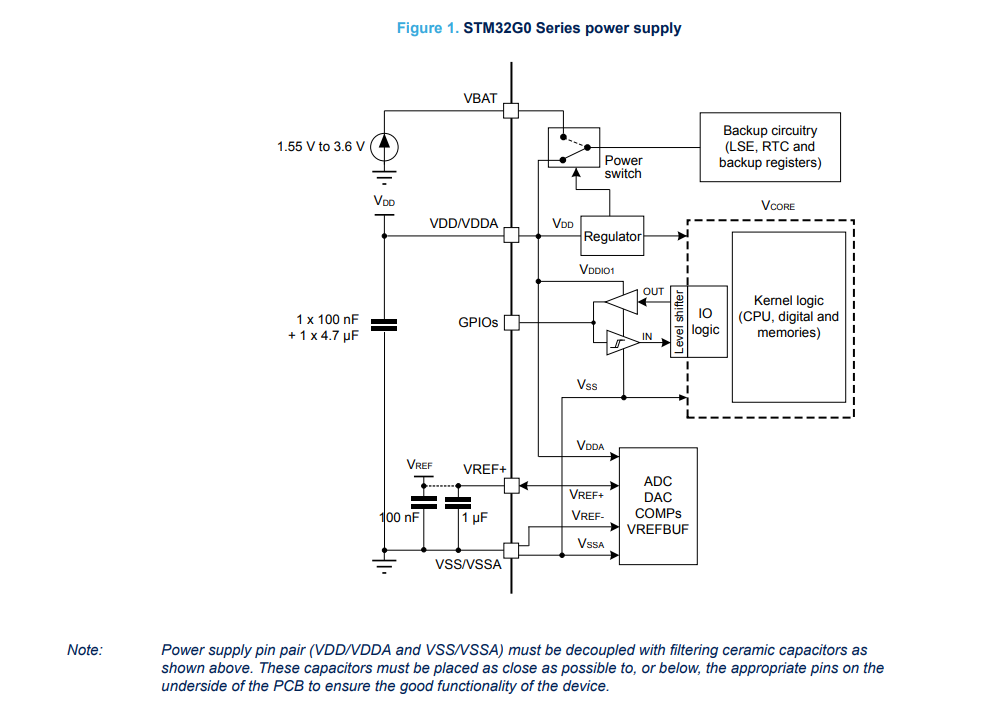
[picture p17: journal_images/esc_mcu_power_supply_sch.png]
esc mcu power supply schematic


so, copying the MCU's power supply schematic with decoupling capacitors and all we get the sum total of... wait for it...

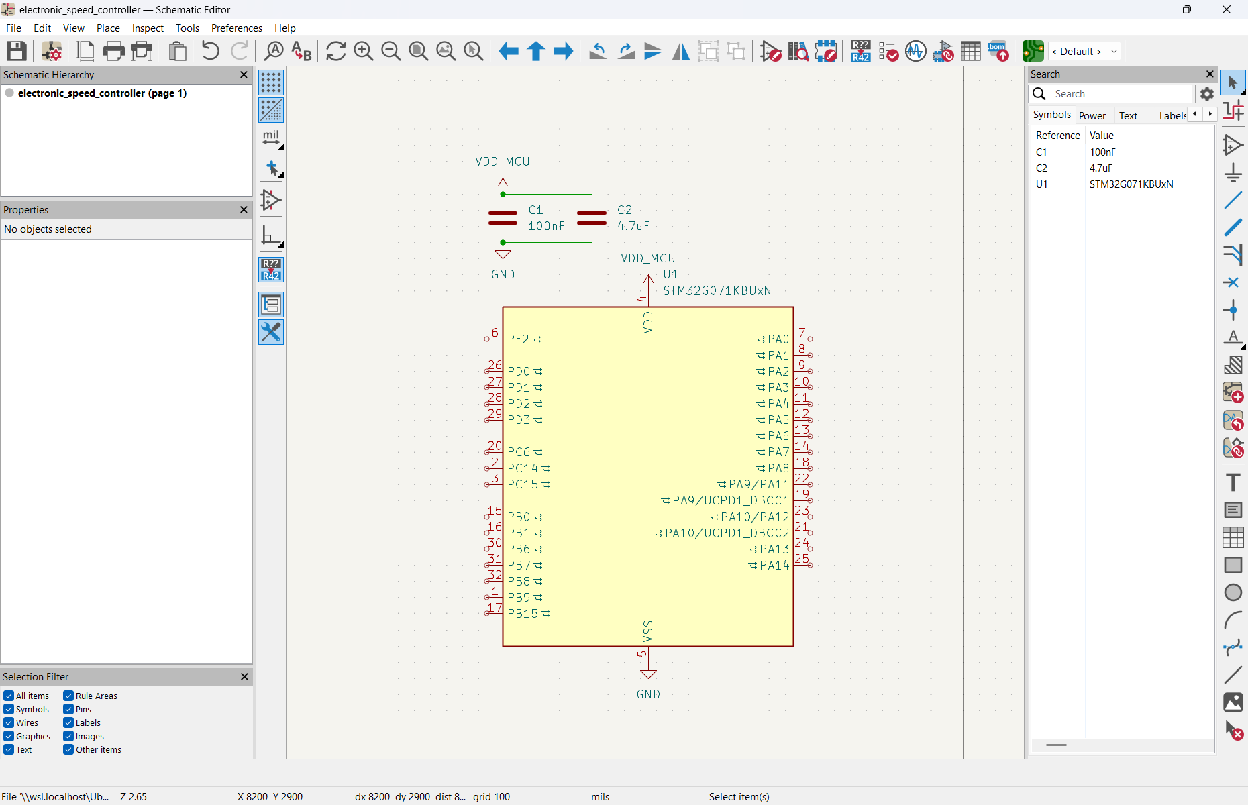
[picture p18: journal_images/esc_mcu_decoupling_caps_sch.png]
esc mcu decoupling caps schematic


**2 capacitors.** (cos on the 32-pin UFQFP, `VREF` and `VBAT` aren't present)

i'm changing out the `HT7530S` for the `HT7533-1` with a SOT-89-3 footprint instead, for _hopefully_ better thermal distribution (also cos it matches the kicad symbol and footprint) and the `TS3480CX50 RFG` for a `HT7550-1`

edited the README to actually say something about the project, with a badly photoshopped sacabambaspis cameo from the internet as a placeholder for not having any images to show

**total time spent: 1.02 hours**

# september 29: designing the propulsion controller ESC pt.6

note: for the ESC schematic (specifically one ESC out of 4 in total on 1 board) i'm adapting from the AM32 hardware reference, but i'll see how i can improve on the design

for the whole module, i'm using the voltage regulators, (the `HT7550-1` and `HT7533-1`) with a connector symbol as a placeholder for the custom solder pads later

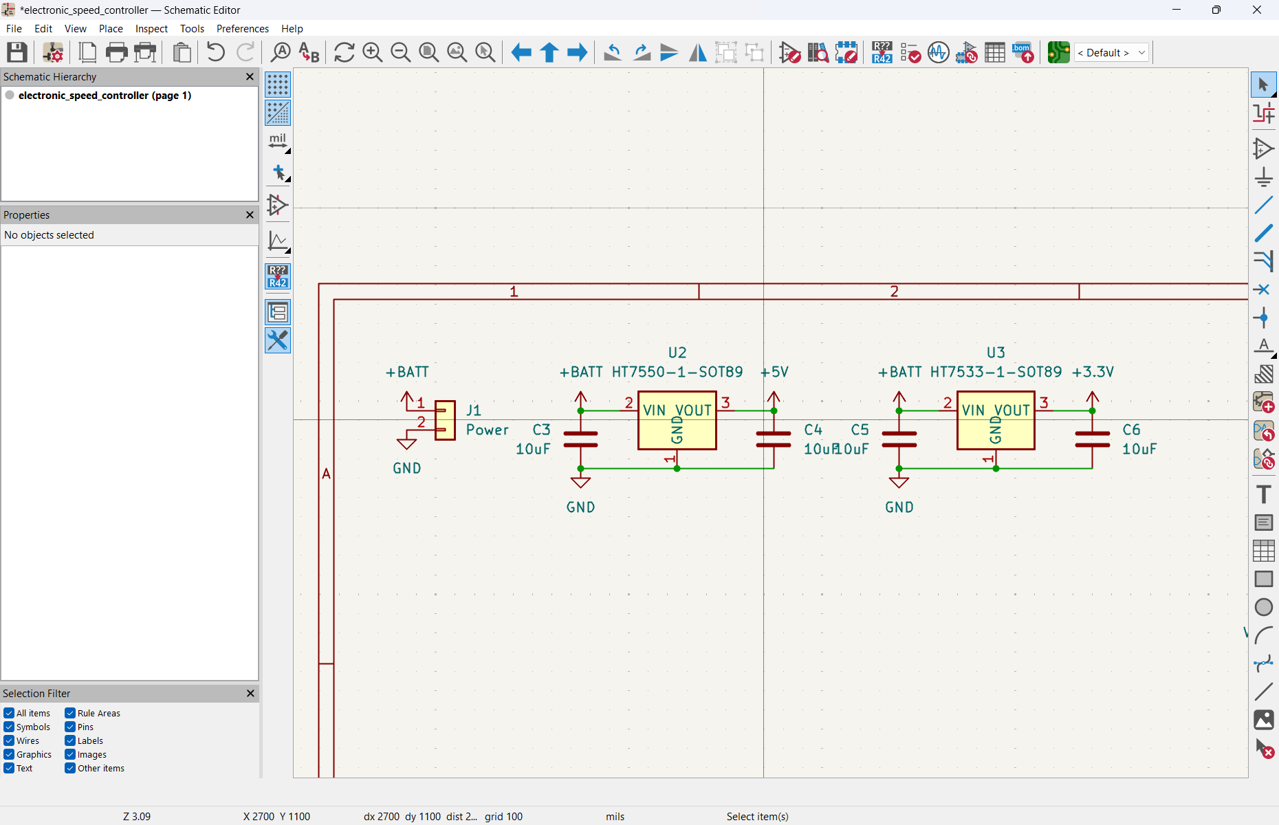
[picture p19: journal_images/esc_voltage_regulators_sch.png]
ESC voltage regulators


the 3-phase motor driver IC itself (the `DRV8300DRGER`)'s just the IC and a couple of caps and diodes

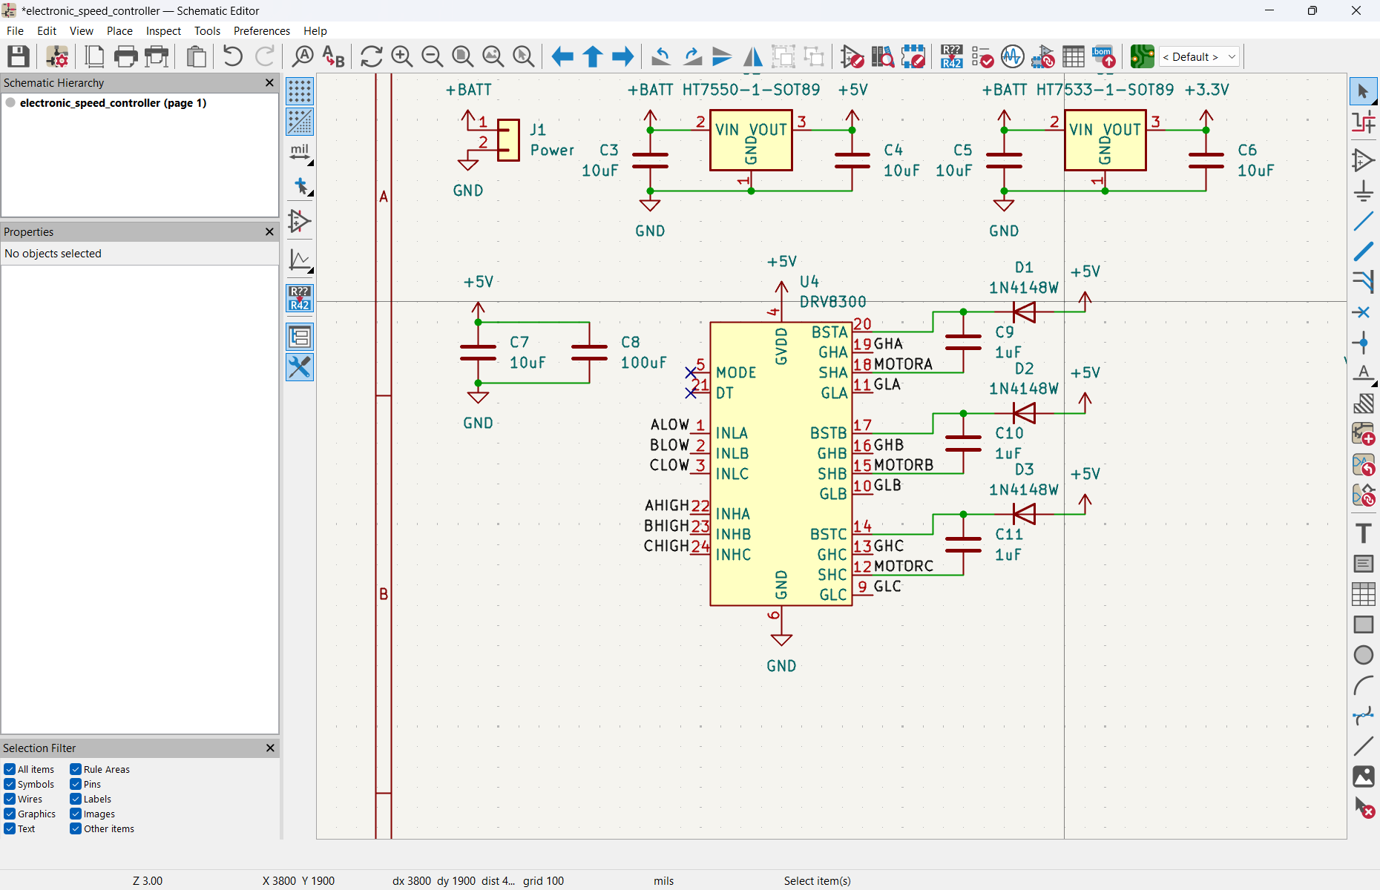
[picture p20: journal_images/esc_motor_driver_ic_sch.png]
ESC motor driver IC


note: changed the MOSFETs to a more capable (albeit slightly overkill for these thrusters one, i'm intending to upgrade the thrusters in mk. 2) [`SIR696DP-T1-GE3`](https://www.digikey.in/en/products/detail/vishay-siliconix/SIR696DP-T1-GE3/6707749)

another note: instead of calling them versions eg. v1, v2, etc. i have chosen to instead pretend i'm iron man and call them mk.1, mk.2, etc

also realized that these new MOSFETs have a drive voltage of 7.5V, so i'll need to find another voltage regulator, adjustable or otherwise for it, and before you ask, no the `HT75xx` series does not have one

i'm going to be using the `TPS7A4501KTTR` for the mosfets (maybe for the rest too)

note: found some errors in the ESC BOM, fixed them but i'm still not sure which `INA180B` i should be using

TBC

**total time spent: 2.13 hours**

# oct 01: designing the propulsion controller ESC pt.7

cos i still have ABSOLUTELY NO IDEA what i should be wiring together for the telemetry pin, i'm leaving that one unconnected (for now, hopefully)

note: noticed there were unnecessary folders and files in the electronics folder, deleted them and the main project files

decided on the [`INA180B1IDBVR`](https://www.digikey.com/en/products/detail/texas-instruments/INA180B1IDBVR/8105876)

back to the schematic!

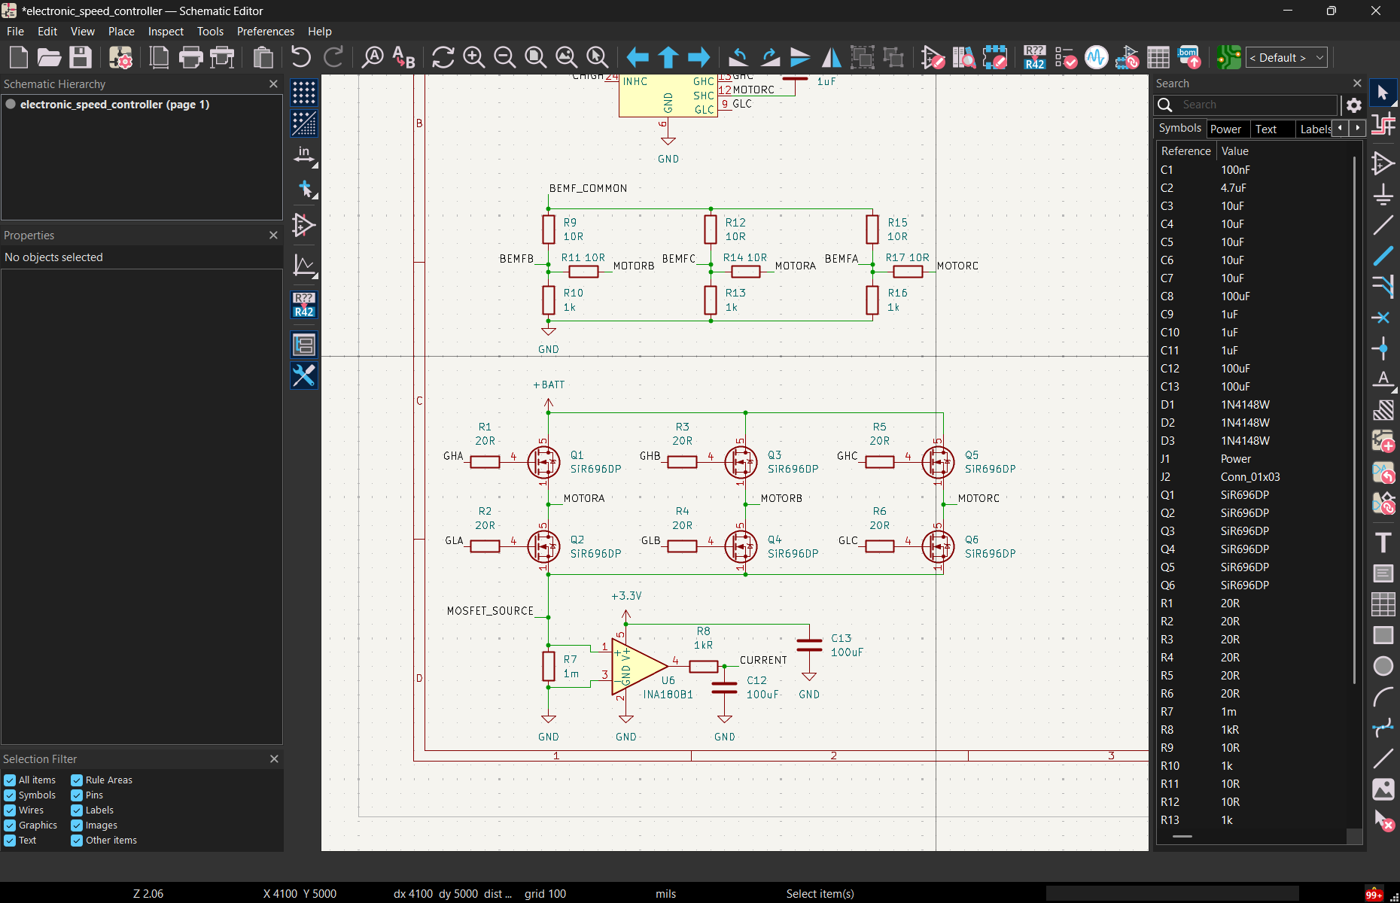
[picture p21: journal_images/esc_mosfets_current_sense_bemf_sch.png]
ESC MOSFETS, current sensor, and BEMF divider


TBC

note: i feel like adding a lot more unnecessary features to the ESC, will do in a bit

**total time spent: 1.27 hours**

# oct 02: AUV hull parts pt.1

so, i sent an email (in 2 parts) to the Blue Robotics sales dept. uhhh we'll see what goes on

> hi! good morning / afternoon / evening to the sales department!
>
> a brief intro on me - i'm Avery, a high school student who's trying to make and document building a hybrid AUV. i call my project meridian and while i'm making relatively smooth progress with the designing stuff so far, i'm at a loss when it comes to funding and sourcing most of the materials. i'm using a program from Hack Club for most of my funding including PCB manufacturing, however some of the materials i need are rather costly, so this is where Blue Robotics comes in! with your help and sponsorship, i could finally get to building it :D i'd love to give Blue Robotics a shoutout as i am genuinely impressed with your open sourced products and their modular designs!!!
>
> my current design for meridian includes the watertight enclosure set (excluding the hull as i'm planning to modify the provided files so i can add some custom attachments to it) as well as a RAILS set for the PCBs i'm currently designing (you can check my progress in the Github repo's contained JOURNAL.md!!!)
>
> i'm absolutely open to discussing further about this and if there's anything i could do in exchange for your help i'd really appreciate it if you could let me know!
>
> thanks,
> Avery

and

> and if this isn't too much to ask, could i maybe ask for an ip camera module???
>
> thanks again,
> Avery (who will be forever grateful if they could get their hands on some parts)

**total time spent: 0.1 hours**

# oct 05: designing the compute module carrier pt.1

note: renamed the kicad project files to compute_module_carrier instead of carrier_module

welllllll... to design the compute module carrier, i'm going to largely ~~steal~~ adapt from [LattePanda's Lite Carrier for the LattePanda Mu](<https://github.com/LattePandaTeam/LattePanda-Mu/tree/main/Electricals/Examples/[DFR1142]Lite%20Carrier%20for%20LattePanda%20Mu(V2)>) (and their symbols and footprints too)

right so now to look at what goes into a carrier module!

one of the issues i'm facing (that i might've mentioned in an earlier entry) is fitting the compute module on the RAILS

so right now i'm going to put all the stuff together to see how much space i have for the carrier

MY LAPTOP JUST CRASHED TwT

welp

what can i do about it

back to work

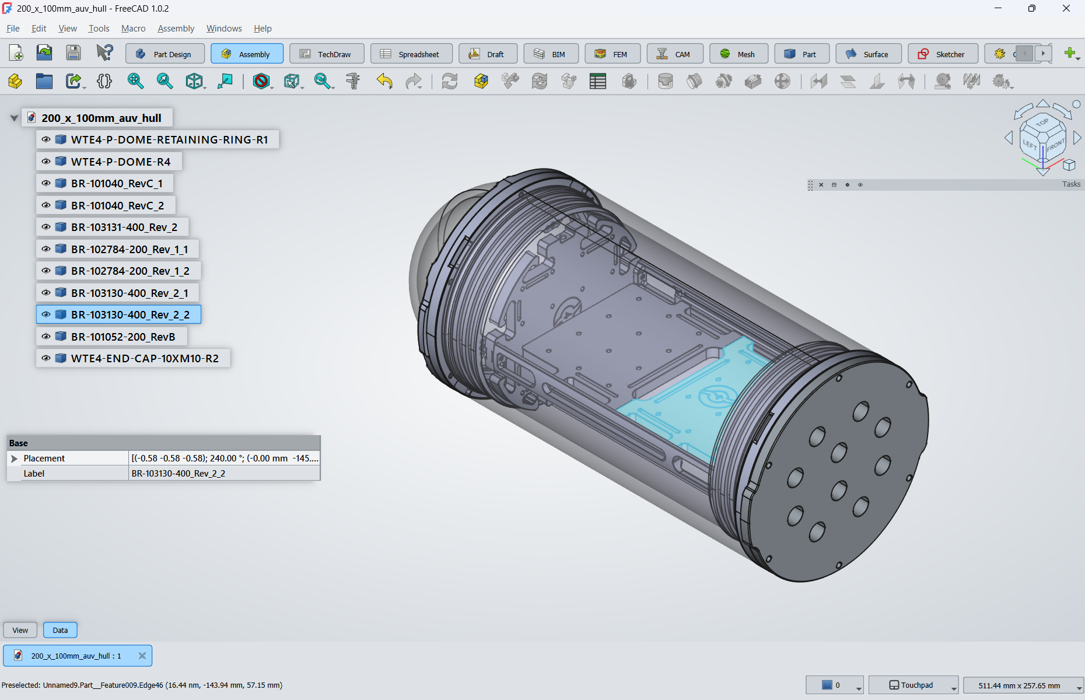
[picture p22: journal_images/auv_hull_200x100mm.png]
AUV hull 200mm length, 100mm diameter


after putting everything together in freecad (btw this is the 200mm ver, i'll expand it to 300mm if i need the extra space) it looks like this, the circular plate at the front's for sensors and stuff, while the rest of the subsystem modules (ie. the compute module carrier, the power management module, and the propulsion control module) sit above or below the rectangular plates

i just realized... i can just add standoffs to the pcb's underside and use the full ~<100mm diameter inside

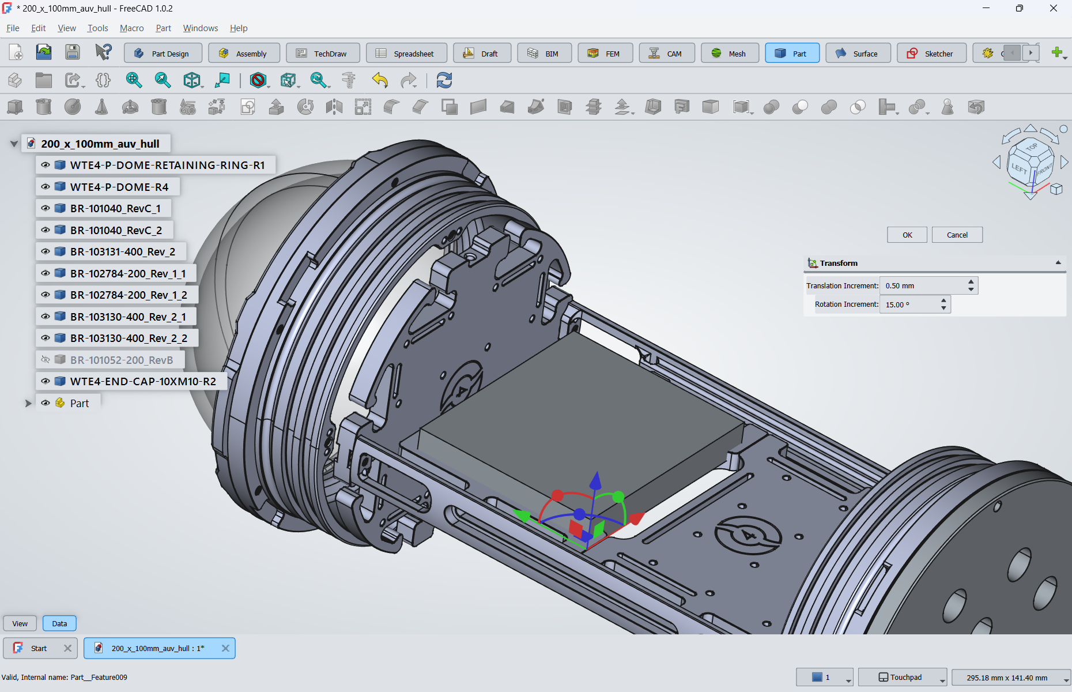
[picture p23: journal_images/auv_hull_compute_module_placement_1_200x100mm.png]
AUV hull 200mm length, 100mm diameter but now it has a badly placed compute module sized box in the center


fyi, the box in the center's based off of the compute module's dimensions (excluding the PCB and the relatively large connector) leaving, not a lot of space for everything else eg. traces, parts

so now that i have a _proper_ idea of how to fit it in there, and where the mounting holes, i can look at the connectors and what to breakout! (thinking of looking at CAN for all these MCUs)

i'm planning to have the following non-negotiables:

- something to connect to the FC
- another something to connect to the sensor board
- something for power, most likely a barrel jack or an XT60
- M.2 for data storage on an SSD
- ethernet for the comms module (mk.2 but why not have it here anyways)

and the more optional stuff:

- a DisplayPort receptacle so i can hook it up to a monitor and debug stuff
- a couple of USB-C and USB-A receptacles to connect random peripherals

also planning to see if i can ask LattePanda for a free compute module, but i'll work that out later

TBC

**total time spent: 1.85 hours**

# oct 07: designing the compute module carrier pt.2

time to start placing things!

note: sometimes i wish i had an extra monitor tbh... switching between virtual desktops just to look at datasheets and reference designs is painful

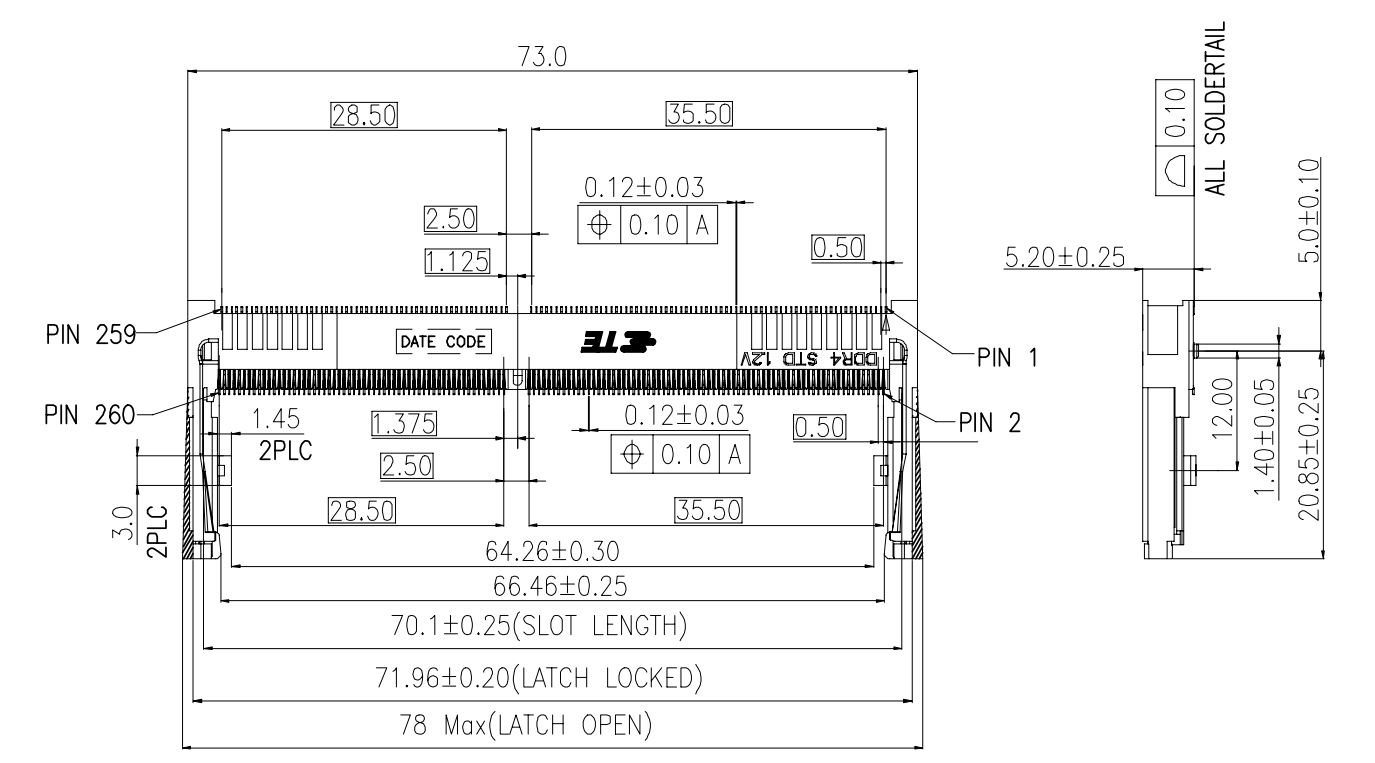
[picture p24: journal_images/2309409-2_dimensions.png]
the 2309409-2 SODIMM 260 position connector dimensions


for the connector (with guidelines mentioned in an earlier entry) i'll be using a low profile one to save space for a potential heatsink (not an ideal solution for cooling in a closed space, i _know_) in particular, the [`2309409-2`](https://www.digikey.my/en/products/detail/te-connectivity-amp-connectors/2309409-2/9564359) with an offset height of 5.2mm and gold plated contacts

note: i'll also be checking if these parts are available in the JLCPCB standard library for PCBA because i do **not** have the confidence to solder most of these high density components, especially considering the PCB's eventual size

looking at it, the footprint LattePanda supplies looks to be about the same as the recommended PCB land pattern for it

its RTC's going to use a CR1220 battery with the [`BAT-HLD-012-SMT-TR`](https://www.digikey.my/en/products/detail/te-connectivity-linx/BAT-HLD-012-SMT-TR/5361776) holder

note: find old laptop later to use as second monitor for references

the carrier's going to take 12V from the power management module over a barrel jack

now i really have to decide what pins to breakout (also mentioned above)

> - something to connect to the FC
> - another something to connect to the sensor board
> - something for power, most likely a barrel jack or an XT60
> - M.2 for data storage on an SSD
> - ethernet for the comms module (mk.2 but why not have it here anyways)
> - a DisplayPort receptacle so i can hook it up to a monitor and debug stuff
> - a couple of USB-C and USB-A receptacles to connect random peripherals

for the displayport stuff, i'd have to use the eDP connector on the compute module itself and connect that via an FPC cable to a displayport and since i don't exactly feel like dealing with that sooooooo i'll be using HDMI instead

**total time spent: 1.1 hours**

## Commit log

2026-09-13 one small commit for me, one giant leap for projectkind
    [meridian.kicad_pcb, meridian.kicad_sch]
2026-09-13 researching AUV components: enclosure edition
    [BOM.csv]
2026-09-14 researching AUV components: thruster edition pt.1
2026-09-15 researching AUV components: thruster edition pt.2 (abridged)
2026-09-18 researching AUV components: enclosure edition pt.2 (the sequel)
2026-09-22 designing the propulsion controller ESC pt.1
2026-09-22 designing the propulsion controller ESC pt.2
    [ESC_BOM.csv]
2026-09-23 designing the propulsion controller ESC pt.3
    [BOM.csv, ESC_BOM.csv, carrier_module.kicad_pcb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]
2026-09-27 designing the propulsion controller ESC pt.4
    [ESC_BOM.csv]
2026-09-28 designing the propulsion controller ESC pt.5
    [ESC_BOM.csv, electronic_speed_controller.kicad_sch]
2026-09-29 designing the propulsion controller ESC pt.6
    [ESC_BOM.csv, electronic_speed_controller.kicad_sch]
2026-10-01 designing the propulsion controller ESC pt.7
    [ESC_BOM.csv, electronic_speed_controller.kicad_sch, power_management_module.kicad_pcb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]
2026-10-02 forgot to commit ESC schematic changes
    [electronic_speed_controller.kicad_sch]
2026-10-04 AUV hull parts pt.1
2026-10-06 designing the compute module carrier pt.1
    [200_x_100mm_auv_hull.FCStd, compute_module_carrier.kicad_pcb, compute_module_carrier.kicad_sch]
2026-10-08 designing the compute module carrier pt.2
    [compute_module_carrier.kicad_sch]
2026-10-13 designing the AUV hull and exterior pt.1
2026-10-13 designing the AUV hull and exterior pt.2
